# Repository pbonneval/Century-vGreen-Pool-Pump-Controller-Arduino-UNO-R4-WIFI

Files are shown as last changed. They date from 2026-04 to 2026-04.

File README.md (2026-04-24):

# Century vGreen Pool Pump Controller






---

## Compatibility

This project is designed specifically for VGreen 270 models (ECM27SQU / ECM27CU) to ensure proper operation and compatibility.

⚠️ Note: Newer VGreen EVO models are not supported, as they use a different control scheme and communication protocol.

Documentation

To help users verify compatibility and better understand the system, the following reference materials are provided:

VGreen 270 Brochure

VGreen 270 User Manual

VGreen 270 Quick Start Guide

These documents can be used to confirm model compatibility and review pump capabilities before implementation.

## 🧊 Enclosure

A custom 3D-printable enclosure is included:

Download Enclosure Files

Features:

Snap-fit design (no screws)
Wall-mount ears
Designed for UNO R4 + RS-485 shield

Also available on Printables:
https://www.printables.com/model/1699991-arduino-uno-r4-wifi-case-with-shield

---

## ⚡ Quick Start

1. Upload the `.ino` to Arduino UNO R4 WiFi
2. Remove OEM Controller 
3. Connect RS-485 on Pump to RS-485 Port on Shield 
3. Connect to WiFi: **POOL PUMP**
4. Open browser:

```text
http://192.168.4.1
```

5. Configure settings and start pump

---

## 🚀 Overview

This project is a **robust, standalone pool pump controller** for my Century / Regal Beloit vGreen 270 variable-speed pump. This controller may be compatible with other Century / Regal Beloit vGreen variable-speed pumps, **implement at your own risk**.

Built on the **Arduino UNO R4 WiFi**, the system communicates over **RS-485 using a custom EPC protocol** and provides a **lightweight web-based UI** for full local control.

Designed for **continuous operation**, the controller uses:

* Non-blocking architecture
* Command queue execution
* Watchdog-style recovery
* Reliable keepalive communication

---

## 🌐 Device Access & WiFi Modes

> ⚠️ **WiFi Compatibility Note**
> Arduino UNO R4 WiFi supports **2.4 GHz only** and is **not compatible with 5 GHz WiFi**.

---

### 🔵 Access Point Mode (Default)

* **SSID:** `POOL PUMP`
* **Password:** *(open network by default)*

Open:

```text
http://192.168.4.1
```

**Notes:**

* No internet required
* “No Internet” warning is normal
* SSID and password are configurable in code
* AP mode is useful for direct local access during setup or troubleshooting

```cpp
const char* ssid     = "POOL PUMP";
const char* password = "";
```

---

### 🟢 Home WiFi Mode (Optional)

```cpp
const char* homeSsid     = "YOUR_HOME_WIFI_SSID";
const char* homePassword = "YOUR_HOME_WIFI_PASSWORD";
```

* IP is assigned automatically by your router using DHCP
* The assigned IP may change after reboot, router restart, or lease renewal
* For reliable access, it is recommended to manage IP assignment from your router

---

### 📌 Recommended: Static IP via Router

Assign a DHCP reservation in your router to keep a consistent IP for the controller.

Example:

```text
192.168.1.50
```

This makes it easier to bookmark the controller and avoids having to rediscover its IP after power cycles.

---

### 🔁 Mode Behavior

* AP mode is always available
* Home WiFi can run in parallel
* AP mode remains a fallback if home WiFi fails

---

### 🕒 Clock & Time Synchronization

The controller uses the onboard RTC for schedules and timekeeping.

#### AP Mode

* No internet access means no NTP time sync
* The RTC is used by itself
* Time may drift over long periods

#### Home WiFi Mode

* NTP time synchronization is available
* Clock accuracy is maintained when internet-connected WiFi is available

📌 Recommendation:

* Use home WiFi for accurate long-term schedule timing
* If running AP-only for extended periods, periodically verify or update the clock

---

## 🖥️ Web Interface

### ▶️ Run Control

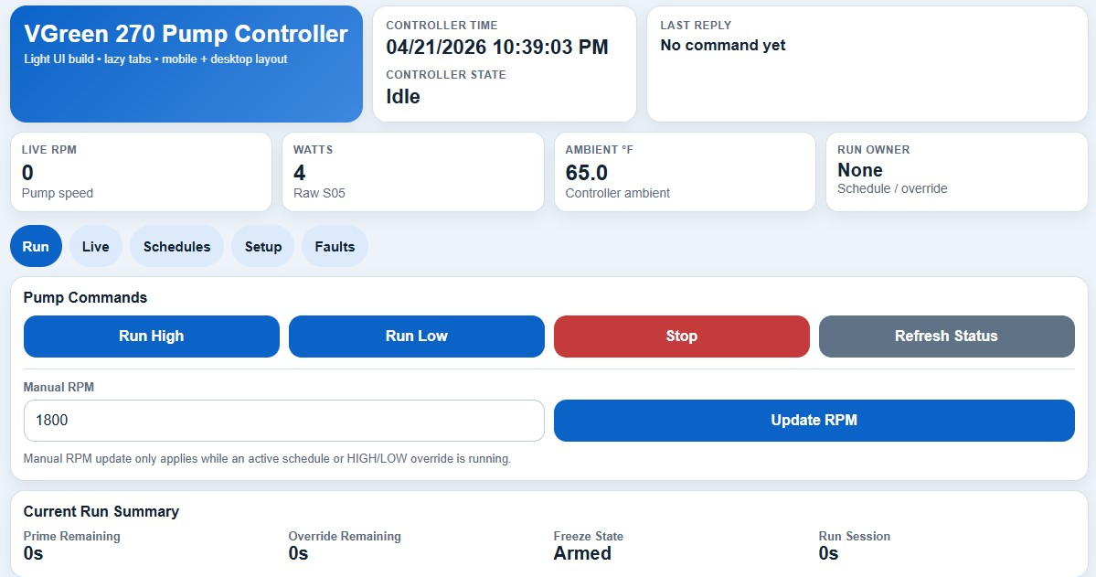
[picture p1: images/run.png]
Run


* Start / Stop
* Override modes
* Manual RPM control

---

### 📊 Live Telemetry

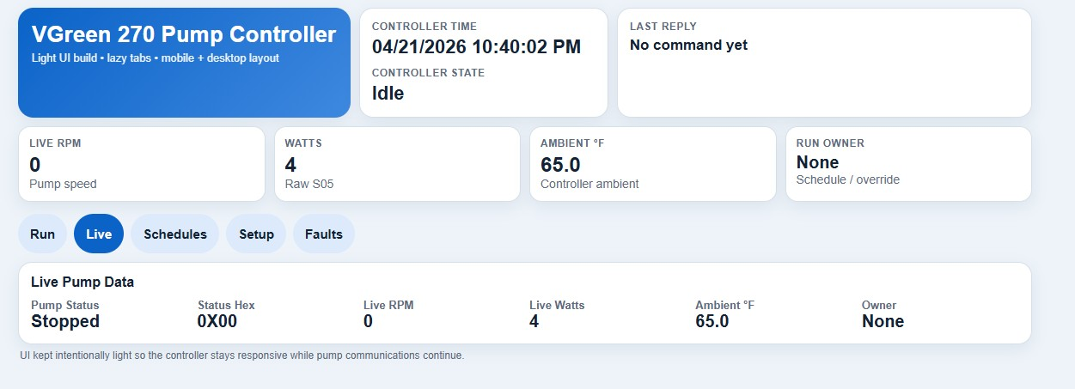
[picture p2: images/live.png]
Live


* RPM
* Watts
* Temperature
* Pump state

---

### 📅 Scheduling

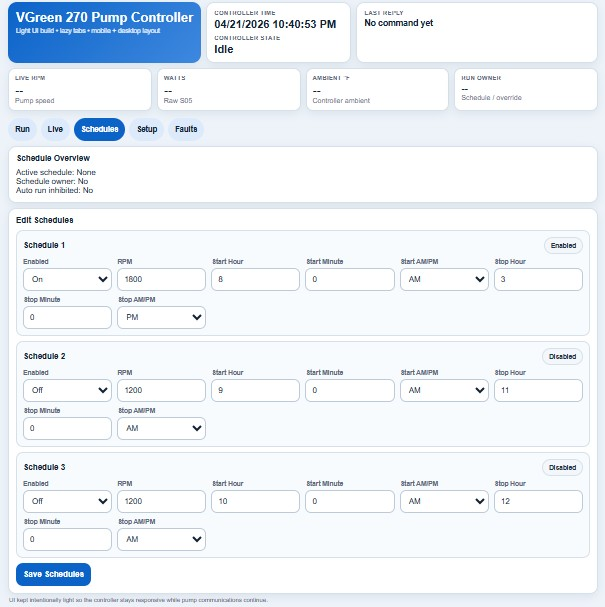
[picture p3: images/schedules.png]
Schedules


* 3 schedules
* Priority-based
* RTC driven
* Prime always enforced

---

### ⚙️ Setup

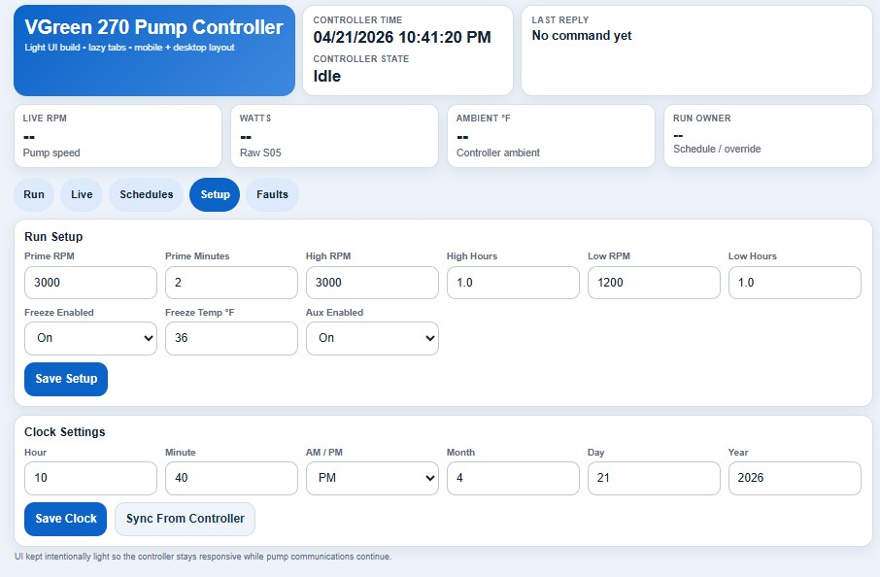
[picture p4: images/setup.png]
Setup


* Prime settings
* Overrides
* Freeze protection
* Clock
* Aux control

---

### ⚠️ Faults

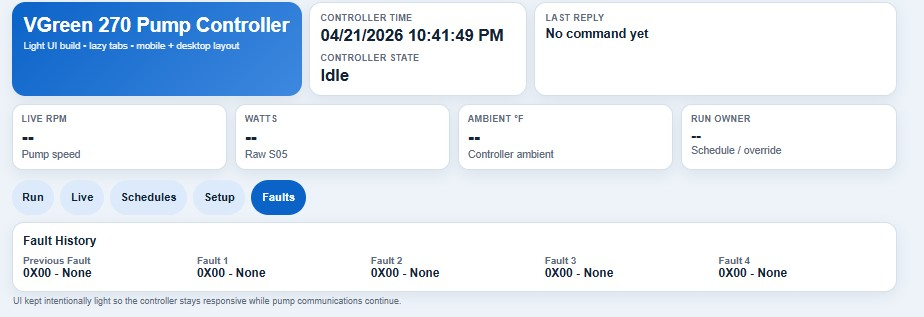
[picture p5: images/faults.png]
Faults


* Active faults
* Previous faults
* Descriptions

---

## 🔌 Hardware

### UNO R4 WiFi Controller

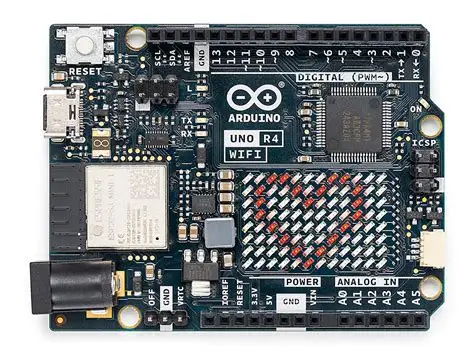
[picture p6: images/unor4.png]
UNO R4


### RS-485 Shield

* Set switches for UART and RS485

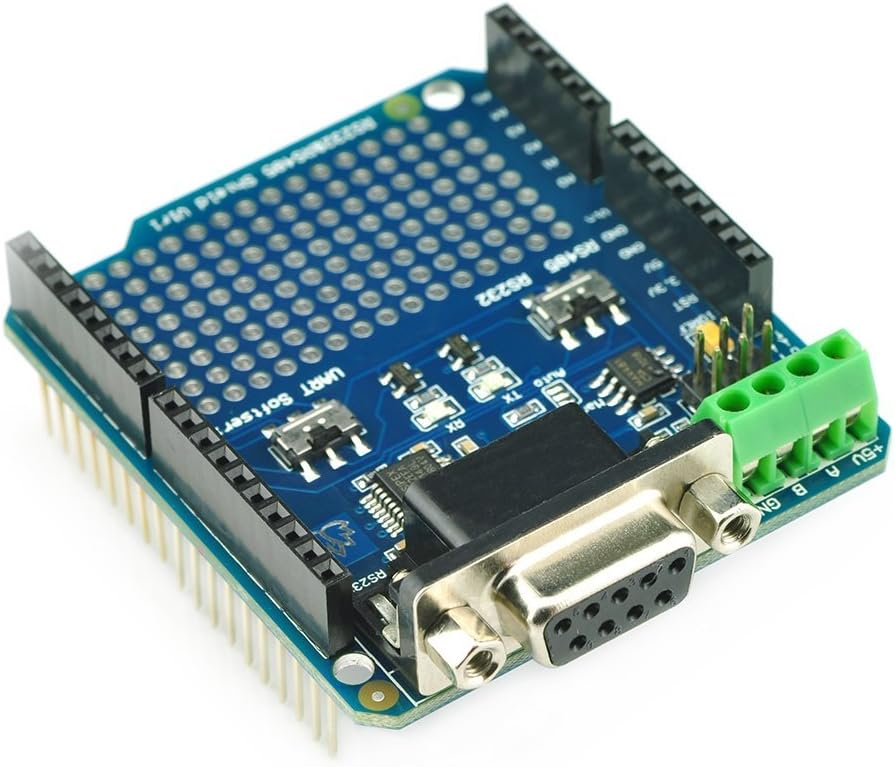
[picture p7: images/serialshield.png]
RS485 Shield


---

### 🔗 RS-485 Wiring

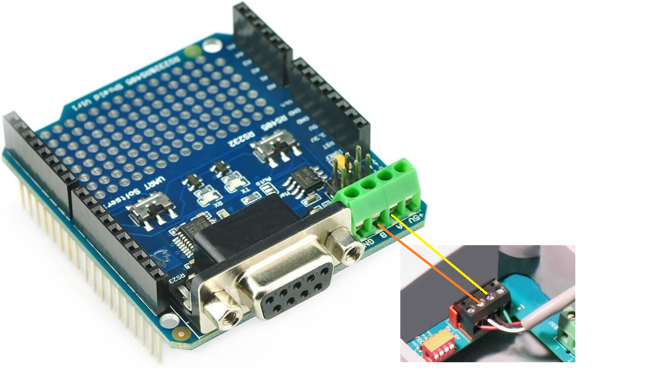
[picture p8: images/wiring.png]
Wiring


| Controller | Pump |
| --- | ---- |
| A / D+ | A |
| B / D- | B |
| GND | GND  |

📌 Notes:

* Swap A/B if no communication
* Use twisted pair where practical
* Keep wires short
* Verify shield switch settings before testing

---

### Pump Interface

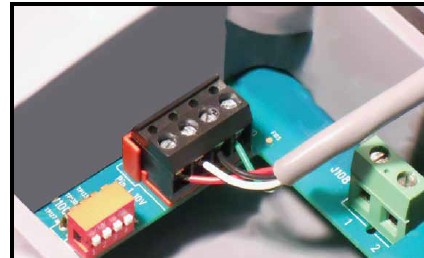
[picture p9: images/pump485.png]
Pump Interface


### Optional TTL Adapter

* UNO Pins 0 and 1 to TX and RX

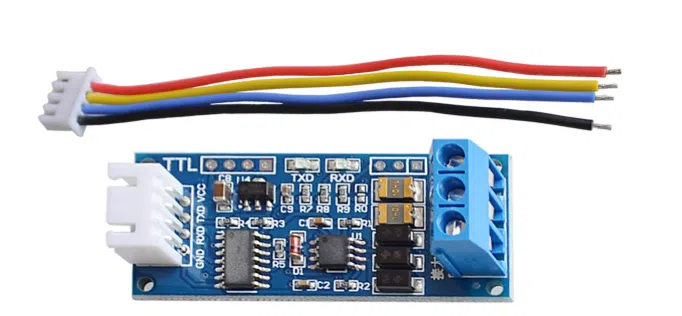
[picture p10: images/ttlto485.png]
TTL Adapter


---

## 🧩 Architecture

* Command queue prevents collisions
* Prime-first startup always enforced
* Ramp engine smooths transitions
* Keepalive prevents timeout
* Schedule engine uses RTC
* Freeze protection monitors temperature
* Watchdog helps prevent lockups

---

## ❄️ Freeze Protection

* Below setpoint for 30 minutes → start pump
* Runs at ~1000 RPM
* Above setpoint for 30 minutes → stop

---

## 🔁 Control Behavior

* Start = **Prime → Run**
* Prime cannot be interrupted
* Overrides > schedules
* Schedules > idle
* STOP blocks restart

---

## 📡 Protocol Notes

* Custom EPC protocol (not Modbus)
* CRC16 (0xA001)
* Pump address: `0x15`
* Requires continuous communication

Reference:
https://www.troublefreepool.com/threads/century-regal-vgreen-motor-automation.238733/

---

## 🛠️ Setup

### 1. Upload Code

* Select UNO R4 WiFi
* Upload sketch

---

### 2. Configure WiFi

```cpp
const char* ssid     = "POOL PUMP";
const char* password = "";
```

Optional:

```cpp
const char* homeSsid     = "...";
const char* homePassword = "...";
```

---

### 3. Connect

**Direct:**

```text
http://192.168.4.1
```

**Home WiFi:**

```text
http://<assigned-ip>
```

---

### 4. Configure System

* Set or verify clock
* Set schedules
* Set prime
* Test pump

---

## 🛠️ Troubleshooting

### No Communication with Pump

* Swap A/B wires
* Verify RS485 switch settings
* Confirm Serial1 wiring if using a TTL adapter
* Check pump address (`0x15`)

---

### Cannot Connect to WiFi

* Ensure the network is 2.4 GHz
* Try AP mode first
* Verify credentials in code

---

### UI Freezes / Pump Stops

* Avoid sending rapid repeated commands
* Allow the controller time to complete actions
* Verify communication timing and keepalive behavior

---

### Time Incorrect

* AP mode does not sync time from the internet
* Use home WiFi for NTP synchronization
* Manually verify or update the clock as needed

---

## 📁 Project Structure

```text
Century-vGreen-Pool-Pump-Controller-Arduino-UNO-R4-WIFI/
├── Century-vGreen-Pool-Pump-Controller-Arduino-UNO-R4-WIFI.ino
├── README.md
├── images/
├── docs/
└── hardware/
```

---

## 🚧 Engineering Notes

* Aux relay tied to pump configuration
* Strict keepalive required
* UI polling impacts performance
* Ramp-down can be more fault-sensitive
* EEPROM and RTC synchronization optimized over time

---

## ⚠️ Disclaimer

This project controls electrical equipment.
Use caution and verify all wiring before operation.

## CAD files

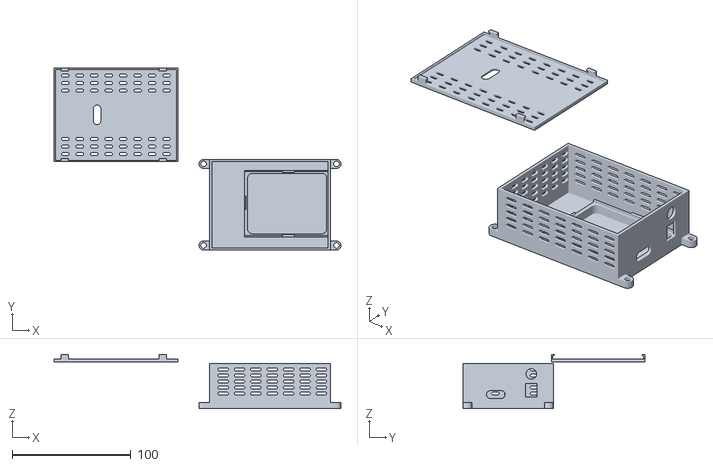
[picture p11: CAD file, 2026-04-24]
enclosure/Arduino R4 Case with Shield.stl
241.3 x 153.0 x 45.7

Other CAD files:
enclosure/Arduino R4 Case with Shield.f3d

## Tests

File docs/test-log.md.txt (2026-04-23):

# 🧪 Test Log – Century VGreen Pool Pump Controller

This document tracks testing, failures, debugging steps, and key discoveries during development of the Arduino UNO R4 WiFi pool pump controller.

---

# 📅 Early Development – Initial Bring-Up (RS-485 & Protocol)

## 🎯 Objective

* Establish communication with pump over RS-485
* Validate EPC protocol behavior
* Confirm command/response structure

---

## 🔍 Initial Issues

### ❌ No Communication

* Pump did not respond to commands
* Occasional garbage data observed

### 🧠 Root Cause

* TX/RX lines were reversed between Arduino and RS-485 module

### 🔧 Fix

* Swapped TX/RX wiring
* Communication established successfully

---

## 🔍 Protocol Validation

### ✅ Observations

* Pump uses **custom EPC protocol (NOT Modbus)**
* CRC confirmed as:

  * **CRC-16 (0xA001 polynomial)**

---

### 🧪 Verified Commands

**STOP Command**

```id="4l5k5f"
TX: 15 42 20 51 7C
RX: 15 42 10 51 68
```

**SET RPM Command**

```id="7ndm7m"
TX: 15 44 20 00 40 1F 89 19
```

---

### 🧠 Findings

* Frame structure:

  * Address + Function + Data + CRC
* Responses include:

  * ACK / NACK behavior

---

## 🔁 Communication Behavior Discovery

### 🔍 Observations

* Pump stops running when communication stops
* Sending a **GO / RUN command alone does NOT start the pump**

---

### 🧠 Findings

* Pump requires **continuous valid communication**
* Timeout occurs at approximately:

  * **~30 seconds**
* A **valid demand (RPM setpoint)** must be established **before** the pump will run
* GO/Run command acts as:

  * Enable / maintain run state
  * NOT a start trigger by itself

---

### 🔧 Required Start Sequence (Discovered Behavior)

1. Send **SET RPM (demand)**
2. Then send **GO / RUN command**
3. Continue sending keep-alive commands

---

### 🔧 Action

* Implemented:

  * Keep-alive command loop
  * Demand-first control logic

---

# 📅 Early Control Testing (Pre-Web UI)

## 🎯 Objective

* Control pump manually via serial commands

---

## 🔍 Observations

### ⚠️ Command Sensitivity

* Some commands require:

  * Repetition
  * Timing delays

### ⚠️ Startup Behavior

* Pump does not instantly run at commanded RPM

---

## 🧠 Findings

* Pump performs internal startup sequence (**Prime Mode**)
* Prime must complete before stable operation

---

## 🔧 Design Decision

* All pump starts must:

  * Enter **Prime Mode**
  * Then transition to target RPM

---

# 📅 Transition to Web UI Control

## 🎯 Objective

* Introduce local web interface for control

---

## 🔍 Initial Issues

### ❌ UI Would Not Fully Load

* Partial page rendering
* Missing sections and data
* Browser timeouts

### ❌ Controller Lockups

* Arduino froze during page load
* Pump communication stopped

---

## 🧠 Findings

* Web server implementation was **blocking**
* Large HTML payload caused:

  * Execution delays
  * Serial communication starvation

---

## 🔧 Actions

* Reduced UI complexity
* Simplified layout
* Improved request handling

---

# 📅 UI Interaction & Command Handling Issues

## 🔍 Observations

### ❌ Rapid Commands Cause Lockup

* Sending multiple commands quickly results in:

  * Controller freeze
  * Loss of communication

### ❌ UI Refresh Impact

* Page reload temporarily interrupts communication
* Can cause missed or delayed commands

---

## 🧠 Findings

* System cannot handle:

  * Back-to-back command execution
* Blocking code sections delay critical tasks

---

## 🔧 Actions

* Introduced command pacing
* Transitioned toward non-blocking logic
* Reduced UI refresh aggressiveness

---

# 📅 Ramp & Power Behavior Testing

## 🎯 Objective

* Prevent faults during RPM transitions

---

## 🔍 Observations

* Large RPM step changes cause:

  * **DC low-voltage faults**
* Ramp down more problematic than ramp up

---

## 🧠 Findings

* Power instability during rapid deceleration
* Behavior likely dependent on load conditions

---

## 🔧 Working Parameters

* Step size: **25 RPM**
* Delay: **250 ms**

⚠️ Testing performed without hydraulic load

---

# 📅 Aux Relay Control Testing

## 🎯 Objective

* Control auxiliary relay via EPC commands

---

## 🔍 Observations

* Relay behavior inconsistent
* Relay sometimes activates:

  * ~3 minutes after prime ends
* ON/OFF behavior occasionally appears inverted
* Commands often require repetition

---

## 🧠 Findings

* Relay control influenced by:

  * Stored pump configuration
  * RPM thresholds
  * Internal timing logic
* Direct commands do not guarantee immediate control

---

## 🔧 Commands Tested

* Write to:

  * Page `0x81`, Address `0x07` (Aux relay control)
* Followed by:

  * STORE CONFIG command

---

## ⚠️ Issues

* Some writes return:

  * `NACK: Data out of range`
* Writes more reliable when:

  * Pump is **stopped**

---

# 📅 UI Lockup Root Cause Identified

## 🔍 Observations

* UI loading causes:

  * Pump communication pause
  * System instability or freeze

---

## 🧠 Findings

* HTTP handling blocks main loop execution
* Serial communication starved during UI processing

---

## 🔧 Actions

* Reduced UI refresh frequency
* Minimized dynamic content
* Avoided polling-heavy design

---

# 📅 Runtime Stability Issue (~28 Minute Failure)

## 🔍 Observations

* System locks up after ~28 minutes:

  * UI inaccessible
  * Pump communication stops

---

## 🧠 Findings

* Likely causes:

  * Memory exhaustion
  * Logging overhead
  * Resource fragmentation

---

## 🔧 Actions

* Removed all logging features
* Simplified runtime loop

---

# 📅 RTC & Time Handling

## 🔍 Observations

* Time resets after power cycle
* RTC overwritten incorrectly on boot

---

## 🧠 Findings

* Boot logic forced RTC update from stored values

---

## 🔧 Actions

* Modified behavior:

  * Read RTC on boot
  * Only update RTC when user saves
* Planned EEPROM persistence

---

# 📅 Time Sync & DST

## 🔍 Observations

* Time offset by 1 hour (DST issue)
* Sync not consistent on reboot

---

## 🔧 Actions

* Implemented:

  * Automatic DST adjustment
  * Time sync on boot
  * UI-based sync button

---

# 📅 EEPROM & Settings Persistence

## 🔍 Observations

* Settings not retained after reboot

---

## 🔧 Actions

* Began implementing EEPROM storage for:

  * Schedules
  * Overrides
  * Clock settings

---

# 📅 Remote Control Attempt (Abandoned)

## 🎯 Objective

* Add cloud-based control via Arduino IoT Cloud

---

## 🔍 Observations

* Required paid plan for variable support
* Increased complexity significantly
* Reduced system stability

---

## 🧠 Decision

* ❌ Abandoned cloud integration
* ✅ Focused on local UI reliability

---

# 📅 UI Finalization & Stability

## 🔍 Observations

* UI stable after reducing load
* Improved responsiveness
* Occasional sensitivity to heavy interaction remains

---

## 🔧 Final Layout Structure

1. Header (clock + sync)
2. Pump controls
3. Live data
4. Overrides
5. Schedules
6. Setup
7. Controller status
8. Fault monitoring

---

# 📊 Key System Behaviors (Critical Knowledge)

## 🔁 Communication

* Pump requires continuous valid commands
* Timeout ≈ **30 seconds**

---

## ⚡ Startup Behavior

* Pump will NOT start from GO/RUN command alone
* A valid **RPM demand must be set first**
* Required sequence:

  1. Set RPM
  2. Send GO/RUN
  3. Maintain keep-alive

---

## ⚡ Prime Behavior

* All starts must:

  * Enter **Prime Mode**
  * Then transition to target RPM

---

## ⛔ Command Handling

* Rapid command execution can:

  * Lock controller
  * Interrupt communication

---

## 🔌 Aux Relay

* Not purely command-driven
* Influenced by:

  * Stored configuration
  * RPM thresholds
  * Internal logic

---

## 🌐 UI Impact

* Heavy UI activity can:

  * Starve serial communication
  * Cause instability

---

# 🧭 Future Testing Areas

* Deterministic aux relay control
* Full-load ramp testing (with plumbing system)
* Freeze protection validation (30-minute logic)
* Fault code verification
* EEPROM reliability and endurance

---

# 🏁 Summary

System status:

* ✅ Stable with local web UI
* ✅ Reliable communication (with command pacing)
* ⚠️ Aux relay behavior not fully deterministic
* ⚠️ Sensitive to blocking operations and UI load

---

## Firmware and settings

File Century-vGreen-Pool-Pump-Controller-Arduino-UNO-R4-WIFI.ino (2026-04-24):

/* VERSION: 1.1 - 2026-04-24 11:35 CT
============================================================
Pool Pump Controller – Arduino UNO R4 WiFi
============================================================

CHANGELOG:
- v1.1:
  - Added Resume Schedule command/button after STOP during active schedule
  - STOP now places active schedule into manual hold-off until Resume Schedule or schedule window changes
  - Run tab Stop button automatically changes to Resume Schedule while schedule hold-off is active

- v1.0:
  - First stable public release
  - Non-blocking control architecture finalized
  - Lightweight web UI with lazy loading
  - EEPROM settings persistence implemented
  - Freeze protection, schedules, overrides, and keepalive integrated

OVERVIEW:
This project implements a fully self-contained pool pump controller
using an Arduino UNO R4 WiFi. The controller communicates with a
variable-speed pump over RS-485 using a custom EPC-style protocol
(not Modbus) and provides a lightweight web-based user interface.

The system is designed for reliability and continuous operation,
with non-blocking control logic, watchdog-style recovery, and
reduced memory pressure to help prevent lockups.

ENTRY POINT:
- setup(): Initializes hardware, WiFi, RTC, EEPROM, and web server
- loop(): Runs cooperative non-blocking control tasks continuously

------------------------------------------------------------
CORE FEATURES:
------------------------------------------------------------
- Local Access Point + Web UI
- RS-485 pump communication using custom EPC protocol
- Prime-first startup for all run conditions
- Non-blocking start sequence and RPM ramping
- 3 programmable schedules with priority (1 > 2 > 3)
- Manual override modes (High / Low)
- Manual RPM update during active schedule/override operation
- Freeze protection based on ambient temperature
- Auxiliary relay control via pump configuration commands
- EEPROM-backed settings persistence
- Optional home WiFi connection and NTP time sync
- Lightweight JSON API endpoints for UI:
    /api/live
    /api/schedules
    /api/setup
    /api/faults

------------------------------------------------------------
HARDWARE INTERFACE:
------------------------------------------------------------
- Controller: Arduino UNO R4 WiFi
- Pump link: RS-485 over Serial1
- Serial settings: 9600 baud, 8-N-1
- RS-485 driver enable pin: GPIO 7 (HIGH = transmit)
- Pump address: 0x15

------------------------------------------------------------
SYSTEM ARCHITECTURE:
------------------------------------------------------------
The controller operates as a state-driven system with cooperative,
non-blocking processes:

1. COMMAND QUEUE
   - User actions are queued and executed sequentially
   - Prevents overlapping commands and command collisions

2. START SEQUENCE
   - Validates pump state
   - Configures auxiliary relay state
   - Stores configuration if needed
   - Starts prime cycle
   - Transitions automatically to target RPM

3. PRIME CONTROL
   - Every start begins with prime mode
   - Prime runs at configured RPM for configured duration
   - RPM changes are blocked until prime completes

4. RAMP ENGINE
   - Smooth RPM transitions up and down
   - Separate ramp behavior for acceleration and deceleration
   - Helps reduce faults from abrupt speed changes

5. KEEPALIVE SYSTEM
   - Periodically re-sends RUN or STOP commands
   - Prevents pump timeout from communication loss

6. SCHEDULE ENGINE
   - Supports 3 schedules with priority handling
   - Starts/stops pump automatically from RTC time
   - Handles overlap and real-time schedule updates

7. OVERRIDE MODES
   - High and Low override modes with duration timers
   - Overrides take priority over schedules
   - Returns to stop, schedule, or freeze mode when complete

8. FREEZE PROTECTION
   - Monitors ambient temperature from pump sensor
   - If below threshold for 30 minutes, starts the pump
   - Runs at fixed RPM until temperature recovers long enough

9. SENSOR + FAULT MONITORING
   - Reads pump status, RPM, power, temperature, and faults
   - Retrieves active and previous fault information
   - Updates UI through lightweight JSON endpoints

10. WATCHDOG-STYLE RECOVERY
   - Detects stalled or lost communication
   - Clears blocked web connections when needed
   - Helps maintain long-term runtime stability

------------------------------------------------------------
WEB UI DESIGN:
------------------------------------------------------------
- Lightweight HTML served from PROGMEM
- Tab-based layout with lazy loading
- Only the active tab polls data
- JSON responses are streamed instead of built as one large buffer
- Designed to reduce UI-related controller lockups

------------------------------------------------------------
PROTOCOL NOTES:
------------------------------------------------------------
- Protocol is custom EPC-style and is not standard Modbus
- CRC uses Modbus-style CRC16, but command framing is proprietary
- Do not use standard Modbus libraries for this controller

------------------------------------------------------------
IMPORTANT NOTES:
------------------------------------------------------------
- This system requires continuous communication with the pump (keepalive)
- Loss of communication for about 30 seconds may stop the pump
- All starts are prime-first by design
- Manual RPM updates are only allowed during active runs
- STOP inhibits auto-restart until Resume Schedule is pressed or the current schedule window changes

------------------------------------------------------------
CONFIGURATION:
------------------------------------------------------------
Before compiling, update:
- Device Access Point SSID/password
- Optional home WiFi credentials

------------------------------------------------------------
DISCLAIMER:
------------------------------------------------------------
This project is provided as-is. Use at your own risk.
Verify wiring, electrical safety, and pump compatibility before
deploying on live equipment.

============================================================
*/

#include <Arduino.h>
#include <WiFiS3.h>
#include <WiFiUdp.h>
#include <NTPClient.h>
#include <EEPROM.h>
#include <string.h>
#include <math.h>
#include <RTC.h>

WiFiServer server(80);
WiFiUDP ntpUDP;
NTPClient timeClient(ntpUDP, "pool.ntp.org", 0, 60000);

// =======================
// WiFi CONFIG (REQUIRED: UPDATE BEFORE USE)
// =======================
const char* ssid         = "YOUR_DEVICE_AP_SSID";       // Example: "POOL_PUMP_CONTROLLER"
const char* password     = "YOUR_DEVICE_AP_PASSWORD";   // Leave "" only if intentionally open

const char* homeSsid     = "YOUR_HOME_WIFI_SSID";       // <-- replace with your WiFi name
const char* homePassword = "YOUR_HOME_WIFI_PASSWORD";   // <-- replace with your password

// =======================
// RS-485 / EPC PROTOCOL
// =======================
#define RS485_DE_PIN 7
const uint8_t PUMP_ADDR          = 0x15;
const uint8_t EPC_ACK_CMD        = 0x20;
const uint8_t EPC_ACK_REPLY      = 0x10;

const uint8_t EPC_FN_GO          = 0x41;
const uint8_t EPC_FN_STOP        = 0x42;
const uint8_t EPC_FN_STATUS      = 0x43;
const uint8_t EPC_FN_SETDEMAND   = 0x44;
const uint8_t EPC_FN_READSENSOR  = 0x45;
const uint8_t EPC_FN_CONFIG_RW   = 0x64;
const uint8_t EPC_FN_STORECFG    = 0x65;

const uint8_t EPC_MODE_SPEED     = 0x00;

// Sensor addresses
const uint8_t EPC_SENSOR_PAGE_AMBIENT_TEMP = 0;
const uint8_t EPC_SENSOR_ADDR_AMBIENT_TEMP = 0x07;
const uint8_t EPC_SENSOR_PAGE_PREV_FAULT   = 0;
const uint8_t EPC_SENSOR_ADDR_PREV_FAULT   = 0x09;
const uint8_t EPC_SENSOR_PAGE_FAULTS       = 1;
const uint8_t EPC_SENSOR_ADDR_FAULT1       = 0x15;
const uint8_t EPC_SENSOR_ADDR_FAULT2       = 0x16;
const uint8_t EPC_SENSOR_ADDR_FAULT3       = 0x17;
const uint8_t EPC_SENSOR_ADDR_FAULT4       = 0x18;
const uint8_t EPC_SENSOR_PAGE_RPM          = 0x03;
const uint8_t EPC_SENSOR_ADDR_RPM          = 0x04;
const uint8_t EPC_SENSOR_PAGE_S05          = 0x00;
const uint8_t EPC_SENSOR_ADDR_S05          = 0x05;

const uint8_t EPC_CONFIG_PAGE1_WRITE       = 0x81;
const uint8_t EPC_CONFIG_ADDR_AUX_RELAY    = 0x07;
const uint8_t EPC_AUX_ON_VALUE             = 0x00;
const uint8_t EPC_AUX_OFF_VALUE            = 0x01;

const unsigned long EPC_IDLE_US            = 4500;
const unsigned long EPC_REPLY_TIMEOUT_MS   = 150;
const unsigned long EPC_POST_TX_DELAY_US   = 300;

// =======================
// FREEZE / RAMP / TIMING
// =======================
const int FREEZE_RUN_RPM = 1000;
const unsigned long FREEZE_CONFIRM_MS = 30UL * 60UL * 1000UL;

const int RAMP_UP_STEP_RPM = 500;
const unsigned long RAMP_UP_DELAY_MS = 500;
const int RAMP_DOWN_STEP_RPM = 25;
const unsigned long RAMP_DOWN_DELAY_MS = 250;

const unsigned long KEEPALIVE_INTERVAL_MS = 1000;
const unsigned long STOP_KEEPALIVE_INTERVAL_MS = 1000;
const unsigned long STATUS_POLL_INTERVAL_MS = 5000;
const unsigned long TELEMETRY_POLL_INTERVAL_MS = 5000;
const unsigned long AUX_RETRY_INTERVAL_MS = 5000;
const unsigned long SETTINGS_CHECKPOINT_INTERVAL_MS = 60000UL;
const unsigned long HOME_WIFI_RETRY_INTERVAL_MS = 30000UL;
const unsigned long NTP_SYNC_INTERVAL_MS = 60UL * 60UL * 1000UL;
const unsigned long WEB_RECOVERY_INTERVAL_MS = 5000UL;
const unsigned long START_SEQUENCE_STEP_INTERVAL_MS = 25;

// =======================
// STRUCTS
// =======================
struct Schedule {
  bool enabled;
  int  speed;
  int  startHour;
  int  startMinute;
  char startAMPM[3];
  int  stopHour;
  int  stopMinute;
  char stopAMPM[3];
};

struct ClockTime {
  int  month;
  int  day;
  int  year;
  int  hour;
  int  minute;
  char ampm[3];
};

// =======================
// GLOBALS
// =======================
ClockTime clockTime;
Schedule sched[3];

bool  freezeEnabled;
int   freezeTemp;
int   auxRPM;
float auxHours;
bool  auxEnabled;
int   primeRPM;
int   primeMinutes;
int   overrideHighRPM;
float overrideHighHours;
int   overrideLowRPM;
float overrideLowHours;

// live state
uint8_t lastPumpStatus = 0xFF;
String  lastPumpStatusText = "Unknown";
String  lastPumpStatusHex  = "0xFF";
String  lastPumpReplyText  = "No command yet";

uint8_t lastPrevFaultCode = 0x00;
String  lastPrevFaultCodeHex = "0x00";
String  lastPrevFaultText = "None";

uint8_t lastFault1Code = 0x00;
String  lastFault1CodeHex = "0x00";
String  lastFault1Text = "None";
uint8_t lastFault2Code = 0x00;
String  lastFault2CodeHex = "0x00";
String  lastFault2Text = "None";
uint8_t lastFault3Code = 0x00;
String  lastFault3CodeHex = "0x00";
String  lastFault3Text = "None";
uint8_t lastFault4Code = 0x00;
String  lastFault4CodeHex = "0x00";
String  lastFault4Text = "None";

int16_t lastAmbientTempRaw = 0;
bool ambientTempValid = false;
uint16_t liveRPMRaw = 0;
uint16_t liveS05Raw = 0;
int livePumpRPM = 0;
int livePumpWatts = 0;

unsigned long lastTelemetryPollMillis = 0;
unsigned long lastStatusPollMillis = 0;
unsigned long lastKeepAliveMillis = 0;
unsigned long lastStopKeepAliveMillis = 0;
unsigned long lastGoodStatusMillis = 0;
unsigned long lastAuxRetryMillis = 0;
unsigned long lastSettingsCheckpointMillis = 0;
unsigned long lastHomeWiFiAttemptMillis = 0;
unsigned long lastNTPSyncMillis = 0;
unsigned long lastWebRecoveryMillis = 0;
unsigned long lastLoopHealthyMillis = 0;

bool auxRelayForcedOff = false;

// timer/session
bool runSessionActive = false;
unsigned long runSessionStartMillis = 0;
unsigned long lastRunSessionDurationMs = 0;
String lastStopReason = "None";

// state machine
enum PumpRunState {
  RUNSTATE_IDLE,
  RUNSTATE_PRIMING,
  RUNSTATE_RUNNING,
  RUNSTATE_FAULT
};
PumpRunState pumpRunState = RUNSTATE_IDLE;

bool pendingRunRequest = false;
unsigned long primeStartMillis = 0;
int requestedTargetRPM = 0;
int currentCommandedRPM = 0;

enum ActiveRunMode {
  ACTIVE_NONE,
  ACTIVE_OVERRIDE_HIGH,
  ACTIVE_OVERRIDE_LOW,
  ACTIVE_OVERRIDE_MANUAL,
  ACTIVE_FREEZE
};
ActiveRunMode activeRunMode = ACTIVE_NONE;
unsigned long activeRunStartMillis = 0;
unsigned long activeRunDurationMs = 0;

// freeze state
bool freezeProtectionActive = false;
unsigned long freezeBelowStartMillis = 0;
unsigned long freezeAboveStartMillis = 0;

// schedule state
uint8_t sensorMonitorStep = 0;
int activeScheduleIndex = -1;
int scheduleRequestedRPM = 0;
bool scheduleOwnsPump = false;
bool autoRunInhibited = false;

// active RPM override of active schedule / active override only
bool activeRPMUpdateEnabled = false;
int  activeRPMUpdateValue = 0;
int  activeRPMUpdateScheduleIndex = -1;

// home wifi / time sync state
bool homeWiFiConnected = false;
String homeWiFiIpText = "Not connected";
bool ntpStarted = false;
bool timeSyncOk = false;
String lastTimeSyncText = "Never";

// command queue
enum QueuedCommandType {
  QUEUED_CMD_NONE,
  QUEUED_CMD_STOP,
  QUEUED_CMD_RUN_HIGH,
  QUEUED_CMD_RUN_LOW,
  QUEUED_CMD_STATUS,
  QUEUED_CMD_AUX_ON,
  QUEUED_CMD_AUX_OFF,
  QUEUED_CMD_MANUAL_RPM,
  QUEUED_CMD_RESUME_SCHEDULE
};
QueuedCommandType queuedCommand = QUEUED_CMD_NONE;
int manualRequestedRPM = 1800;

// non-blocking start / ramp
enum StartSequenceState {
  START_IDLE,
  START_STATUS,
  START_AUX,
  START_STORE,
  START_SET_RPM,
  START_GO,
  START_COMPLETE,
  START_FAILED
};
StartSequenceState startSequenceState = START_IDLE;
bool startSequenceActive = false;
int startSequenceTargetRPM = 0;
unsigned long lastStartSequenceStepMillis = 0;

enum RampState {
  RAMP_IDLE,
  RAMP_ACTIVE
};
RampState rampState = RAMP_IDLE;
bool rampActive = false;
int rampTargetRPM = 0;
int rampCurrentRPM = 0;
unsigned long lastRampStepMillis = 0;

// =======================
// FORWARDS
// =======================
void servicePumpKeepAlive();
void servicePumpStopKeepAlive();
void processStartSequence();
void processRampSequence();
void processPrimeTransition();
void processActiveRunTimeout();
void processFreezeProtection();
void processSchedules();
void processPumpCommands();
void pollPumpStatusIfDue();
void refreshAllSensorMonitoring();
void refreshLiveTelemetry();
void updateAuxRelayControl();
void serviceWatchdogRecovery();
void syncClockFromNTPIfNeeded();
void serviceHomeWiFi();
void checkpointAllSettingsToEEPROM();
bool activeRPMUpdateAllowed();
void clearActiveRPMUpdate();
String jsonEscape(const String& in);

// =======================
// RTC HELPERS
// =======================
Month intToMonth(int m) {
  switch (m) {
    case 1: return Month::JANUARY;
    case 2: return Month::FEBRUARY;
    case 3: return Month::MARCH;
    case 4: return Month::APRIL;
    case 5: return Month::MAY;
    case 6: return Month::JUNE;
    case 7: return Month::JULY;
    case 8: return Month::AUGUST;
    case 9: return Month::SEPTEMBER;
    case 10: return Month::OCTOBER;
    case 11: return Month::NOVEMBER;
    default: return Month::DECEMBER;
  }
}

int monthToInt(Month m) {
  return Month2int(m);
}

int calcDayOfWeek(int year, int month, int day) {
  static int t[] = {0,3,2,5,0,3,5,1,4,6,2,4};
  if (month < 3) year -= 1;
  return (year + year/4 - year/100 + year/400 + t[month-1] + day) % 7;
}

DayOfWeek intToDayOfWeek(int dow) {
  switch (dow) {
    case 0: return DayOfWeek::SUNDAY;
    case 1: return DayOfWeek::MONDAY;
    case 2: return DayOfWeek::TUESDAY;
    case 3: return DayOfWeek::WEDNESDAY;
    case 4: return DayOfWeek::THURSDAY;
    case 5: return DayOfWeek::FRIDAY;
    default: return DayOfWeek::SATURDAY;
  }
}

String twoDigits(int v) {
  if (v < 10) return "0" + String(v);
  return String(v);
}

String rtcDateTimeString() {
  RTCTime now;
  RTC.getTime(now);

  String s = "";
  s += twoDigits(monthToInt(now.getMonth()));
  s += "/";
  s += twoDigits(now.getDayOfMonth());
  s += "/";
  s += String(now.getYear());
  s += " ";

  int hour24 = now.getHour();
  int hour12 = hour24 % 12;
  if (hour12 == 0) hour12 = 12;

  s += String(hour12);
  s += ":";
  s += twoDigits(now.getMinutes());
  s += ":";
  s += twoDigits(now.getSeconds());
  s += (hour24 >= 12) ? " PM" : " AM";
  return s;
}

void copyRTCToClockSettings() {
  RTCTime now;
  RTC.getTime(now);
  clockTime.month = monthToInt(now.getMonth());
  clockTime.day = now.getDayOfMonth();
  clockTime.year = now.getYear();
  int hour24 = now.getHour();
  int hour12 = hour24 % 12;
  if (hour12 == 0) hour12 = 12;
  clockTime.hour = hour12;
  clockTime.minute = now.getMinutes();
  strcpy(clockTime.ampm, (hour24 >= 12) ? "PM" : "AM");
}

void setRTCFromClockSettings() {
  int hour24 = clockTime.hour % 12;
  if (strcmp(clockTime.ampm, "PM") == 0) hour24 += 12;
  int dow = calcDayOfWeek(clockTime.year, clockTime.month, clockTime.day);
  RTCTime t(clockTime.day, intToMonth(clockTime.month), clockTime.year,
            hour24, clockTime.minute, 0,
            intToDayOfWeek(dow), SaveLight::SAVING_TIME_INACTIVE);
  RTC.setTime(t);
}

// =======================
// BASIC HELPERS
// =======================
bool isValidAMPM(const char* s) {
  return strcmp(s, "AM") == 0 || strcmp(s, "PM") == 0;
}

void setAMPM(char* dest, const String& src) {
  if (src == "PM") strcpy(dest, "PM");
  else strcpy(dest, "AM");
}

int16_t rawToSigned16(uint16_t raw) { return (int16_t)raw; }
float ambientTempC() { return ((float)lastAmbientTempRaw) / 128.0f; }
float ambientTempF() { return (ambientTempC() * 9.0f / 5.0f) + 32.0f; }
String formatFloat1(float v) { return String(v, 1); }

String formatDurationSeconds(unsigned long seconds) {
  unsigned long hours = seconds / 3600UL;
  unsigned long minutes = (seconds % 3600UL) / 60UL;
  unsigned long secs = seconds % 60UL;
  String s = "";
  if (hours > 0) { s += String(hours); s += "h "; }
  if (minutes > 0 || hours > 0) { s += String(minutes); s += "m "; }
  s += String(secs);
  s += "s";
  return s;
}

String jsonEscape(const String& in) {
  String out;
  out.reserve(in.length() + 8);
  for (size_t i = 0; i < in.length(); i++) {
    char c = in[i];
    if (c == '\\' || c == '"') {
      out += '\\'; out += c;
    } else if (c == '\n') out += "\\n";
    else if (c == '\r') out += "\\r";
    else out += c;
  }
  return out;
}

// =======================
// DEFAULTS / EEPROM
// =======================
void initDefaults() {
  clockTime.month = 4;
  clockTime.day = 21;
  clockTime.year = 2026;
  clockTime.hour = 12;
  clockTime.minute = 0;
  strcpy(clockTime.ampm, "PM");

  for (int i = 0; i < 3; i++) {
    sched[i].enabled = true;
    sched[i].speed = 1200;
    sched[i].startHour = 8 + i;
    sched[i].startMinute = 0;
    strcpy(sched[i].startAMPM, "AM");
    sched[i].stopHour = 10 + i;
    sched[i].stopMinute = 0;
    strcpy(sched[i].stopAMPM, "AM");
  }

  freezeEnabled = false;
  freezeTemp = 36;
  auxRPM = 2000;
  auxHours = 1.0;
  auxEnabled = true;
  primeRPM = 3000;
  primeMinutes = 3;
  overrideHighRPM = 3450;
  overrideHighHours = 1.0;
  overrideLowRPM = 1200;
  overrideLowHours = 1.0;
}

bool settingsLookValid() {
  if (clockTime.month < 1 || clockTime.month > 12) return false;
  if (clockTime.day < 1 || clockTime.day > 31) return false;
  if (clockTime.year < 2000 || clockTime.year > 2099) return false;
  if (clockTime.hour < 1 || clockTime.hour > 12) return false;
  if (clockTime.minute < 0 || clockTime.minute > 59) return false;
  if (!isValidAMPM(clockTime.ampm)) return false;

  for (int i = 0; i < 3; i++) {
    if (sched[i].speed < 600 || sched[i].speed > 3450) return false;
    if (sched[i].startHour < 1 || sched[i].startHour > 12) return false;
    if (sched[i].startMinute < 0 || sched[i].startMinute > 59) return false;
    if (!isValidAMPM(sched[i].startAMPM)) return false;
    if (sched[i].stopHour < 1 || sched[i].stopHour > 12) return false;
    if (sched[i].stopMinute < 0 || sched[i].stopMinute > 59) return false;
    if (!isValidAMPM(sched[i].stopAMPM)) return false;
  }

  if (freezeTemp < 32 || freezeTemp > 90) return false;
  if (auxRPM < 600 || auxRPM > 3450) return false;
  if (auxHours < 0.5 || auxHours > 24.0) return false;
  if (primeRPM < 1500 || primeRPM > 3450) return false;
  if (primeMinutes < 1 || primeMinutes > 10) return false;
  if (overrideHighRPM < 600 || overrideHighRPM > 3450) return false;
  if (overrideHighHours < 0.5 || overrideHighHours > 24.0) return false;
  if (overrideLowRPM < 600 || overrideLowRPM > 3450) return false;
  if (overrideLowHours < 0.5 || overrideLowHours > 24.0) return false;
  return true;
}

void saveSettings() {
  int addr = 0;
  EEPROM.put(addr, clockTime);         addr += sizeof(clockTime);
  for (int i = 0; i < 3; i++) { EEPROM.put(addr, sched[i]); addr += sizeof(Schedule); }
  EEPROM.put(addr, freezeEnabled);     addr += sizeof(freezeEnabled);
  EEPROM.put(addr, freezeTemp);        addr += sizeof(freezeTemp);
  EEPROM.put(addr, auxRPM);            addr += sizeof(auxRPM);
  EEPROM.put(addr, auxHours);          addr += sizeof(auxHours);
  EEPROM.put(addr, auxEnabled);        addr += sizeof(auxEnabled);
  EEPROM.put(addr, primeRPM);          addr += sizeof(primeRPM);
  EEPROM.put(addr, primeMinutes);      addr += sizeof(primeMinutes);
  EEPROM.put(addr, overrideHighRPM);   addr += sizeof(overrideHighRPM);
  EEPROM.put(addr, overrideHighHours); addr += sizeof(overrideHighHours);
  EEPROM.put(addr, overrideLowRPM);    addr += sizeof(overrideLowRPM);
  EEPROM.put(addr, overrideLowHours);  addr += sizeof(overrideLowHours);
}
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
void loop() {
  lastLoopHealthyMillis = millis();

  processStartSequence();
  processRampSequence();
  processPrimeTransition();
  processPumpCommands();
  servicePumpKeepAlive();
  servicePumpStopKeepAlive();
  pollPumpStatusIfDue();
  processActiveRunTimeout();
  processFreezeProtection();
  processSchedules();
  serviceHomeWiFi();
  syncClockFromNTPIfNeeded();
  serviceWatchdogRecovery();

  if (millis() - lastSettingsCheckpointMillis >= SETTINGS_CHECKPOINT_INTERVAL_MS) {
    lastSettingsCheckpointMillis = millis();
    checkpointAllSettingsToEEPROM();
  }

  serviceWebServer();
}

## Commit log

2026-04-23 Add RS485 wiring diagram
2026-04-23 Add wiring diagram to hardware section
2026-04-23 Add TEST_LOG with full development history and pump behavior notes
2026-04-24 Add custom UNO R4 enclosure (STL + STEP + images)
    [Arduino R4 Case with Shield.f3d, Arduino R4 Case with Shield.stl]
2026-04-24 Update README with Enclosure details and link
2026-04-24 Update: replaced .ino with latest build (schedule resume + UI fix)
    [Century-vGreen-Pool-Pump-Controller-Arduino-UNO-R4-WIFI.ino]
